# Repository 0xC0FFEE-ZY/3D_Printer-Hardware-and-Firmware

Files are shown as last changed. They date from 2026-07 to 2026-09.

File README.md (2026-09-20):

# 0xC0FFEE_ZY_3DPrinter

> **本仓库所有硬件已制作出实物并正常运行。** 

自制的 3D 打印机开源项目，包含整机三维建模、主板与电机驱动电路设计、Marlin 固件、CAD 结构件等。

- 可观看视频：https://b23.tv/UroBLIZ

## 仓库内容

| 目录 / 文件 | 说明 |
| --- | --- |
| `三维建模` | 本 3D 打印机整体三维结构建模；打印机屏幕外壳（适用于 MKS TFT35） |
| `硬件设计_工程文件（原理图+PCB）` | 嘉立创工程，本 3D 打印机的主板、电机驱动电路设计 |
| `Chinese_Version_Configured_Marlin2.1.3` | 本打印机配套固件 |
| `CAD图纸_3D打印机结构件` | 本打印机的一些结构件，可以找商家加工定制 |
| `XY_DrawCircles` | XY 轴测试程序 |

## 教程视频

关于本 3D 打印机详细的机械设计、电路设计介绍，可访问：https://b23.tv/Fq90FVm

视频中包括本 3D 打印机的结构三维动画，使用Solidworks运动算例制作。

- B站用户名 **0xC0FFEE_ZY**（抖音同名）

## 版权与许可

- Copyright (C) 2026 0xC0FFEE_ZY
- 本项目硬件电路及机械结构由 0xC0FFEE_ZY 设计。
- 软件基于 Marlin 固件（Copyright (C) Camiel Gubbels / Erik van der Zalm / MarlinFirmware，GPLv3 许可）。
- 本项目同样遵循 [GPLv3]许可。
- 如引用、转载或分发，须保留本版权声明和署名。
- 项目仓库：<https://github.com/0xC0FFEE-ZY/3D_Printer-Hardware-and-Firmware>
- 立创开源硬件平台：<https://oshwhub.com/zy_202411/zi-zhi-3d-da-yin-ji-ying-jian-dian-lu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>

                                                                   2026.9.20 By 0xC0FFEE_ZY

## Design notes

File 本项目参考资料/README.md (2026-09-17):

#
# 参考资料
#

本文件夹是本人制作这台3D打印机时参考过的一些资料，包括芯片手册，一些开源电路原理图等。希望对你们有些帮助。

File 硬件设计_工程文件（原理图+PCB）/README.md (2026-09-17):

 ================================================================================================================
 # Copyright (C) 2026 0xC0FFEE_ZY
 #
 # 本文件夹为 3D 打印机硬件工程文件，可配套教程视频使用。
 # 包括 步进电机驱动，打印机主板、线路转接板 的硬件工程文件，使用 嘉立创EDA专业版 绘制。
 #
 # 本文件夹提供了电路原理图 PDF 版本，可以快速浏览原理图。
 #
 # 硬件工程开源遵循GPLv3许可
 # 如引用、转载或分发，必须保留本版权声明和署名。
 #
 # 作者：0xC0FFEE_ZY
 # 2026.6.19
 ================================================================================================================

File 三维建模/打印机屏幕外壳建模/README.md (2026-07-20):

#
# 3D打印机屏幕外壳建模文件
#

这是本人的3D打印机屏幕外壳建模文件，包含4个零件和一个装配体文件。  适用于MKS TFT35串口屏（SD卡侧插版）

屏幕外壳总共由3个零件组成。装配体演示了3个零件之间的配合关系，安装的时候可以参考。

                                                                       0xC0FFEE_ZY
                                                                       2026.7.21

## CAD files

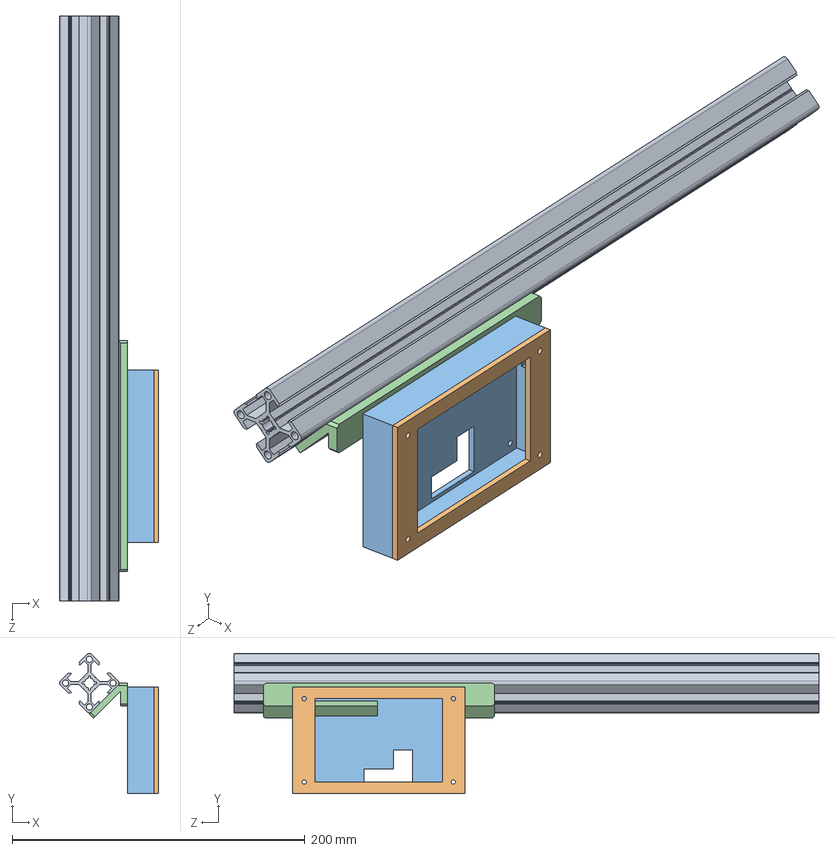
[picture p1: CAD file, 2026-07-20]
三维建模/打印机屏幕外壳建模/打印机屏幕外壳装配体.SLDASM
67.6 x 96.0 x 400.0 mm
屏幕座子支架
打印机屏幕底板
屏幕上盖
TXCK-H6-3030-L400

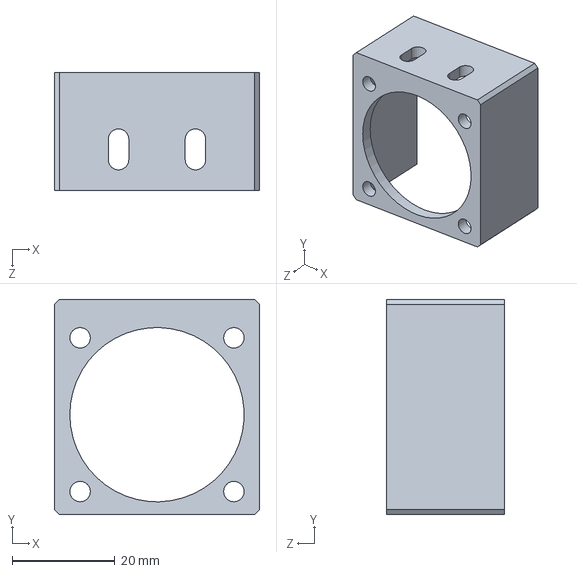
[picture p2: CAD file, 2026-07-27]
三维建模/喉管风扇外壳_风扇固定.SLDPRT
40.0 x 42.0 x 23.0 mm

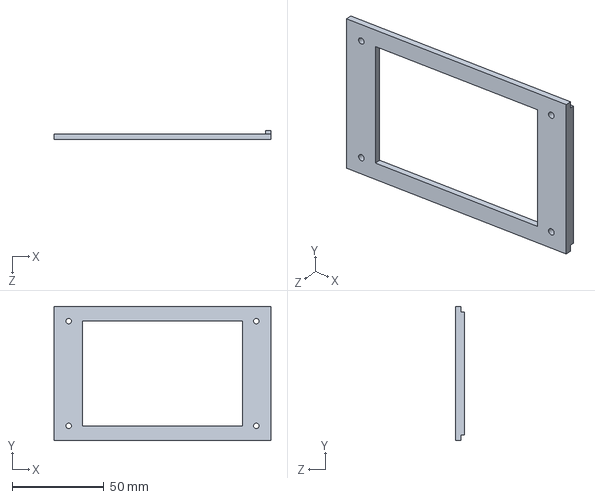
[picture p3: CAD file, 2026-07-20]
三维建模/打印机屏幕外壳建模/零件/屏幕上盖.SLDPRT
118.0 x 73.0 x 5.00 mm

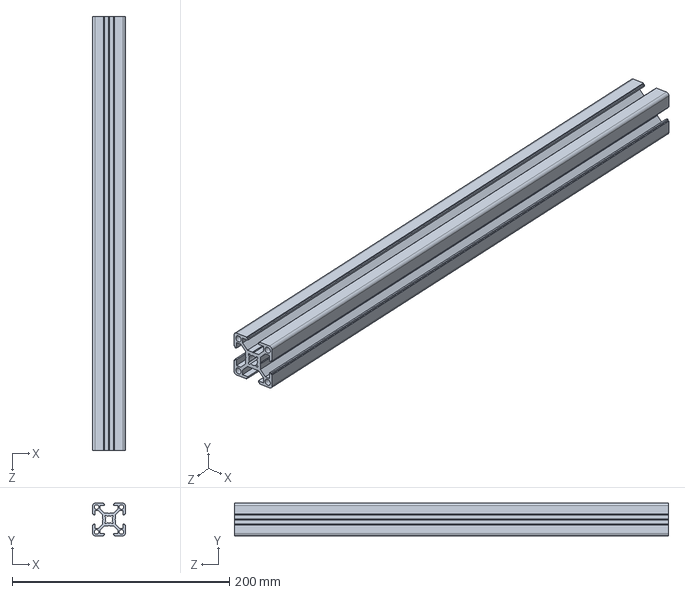
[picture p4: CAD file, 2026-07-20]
三维建模/打印机屏幕外壳建模/零件/TXCK-H6-3030-L400.SLDPRT
30.0 x 30.0 x 400.0 mm

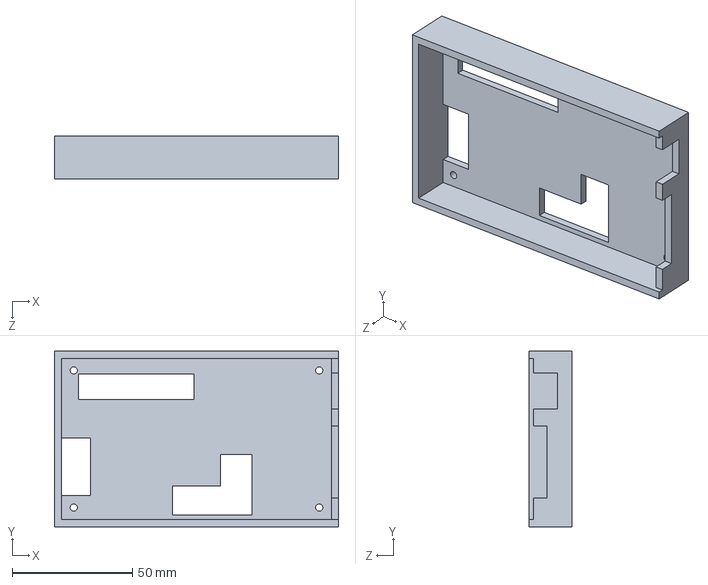
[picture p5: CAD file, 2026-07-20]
三维建模/打印机屏幕外壳建模/零件/打印机屏幕底板.SLDPRT
118.0 x 73.0 x 18.0 mm

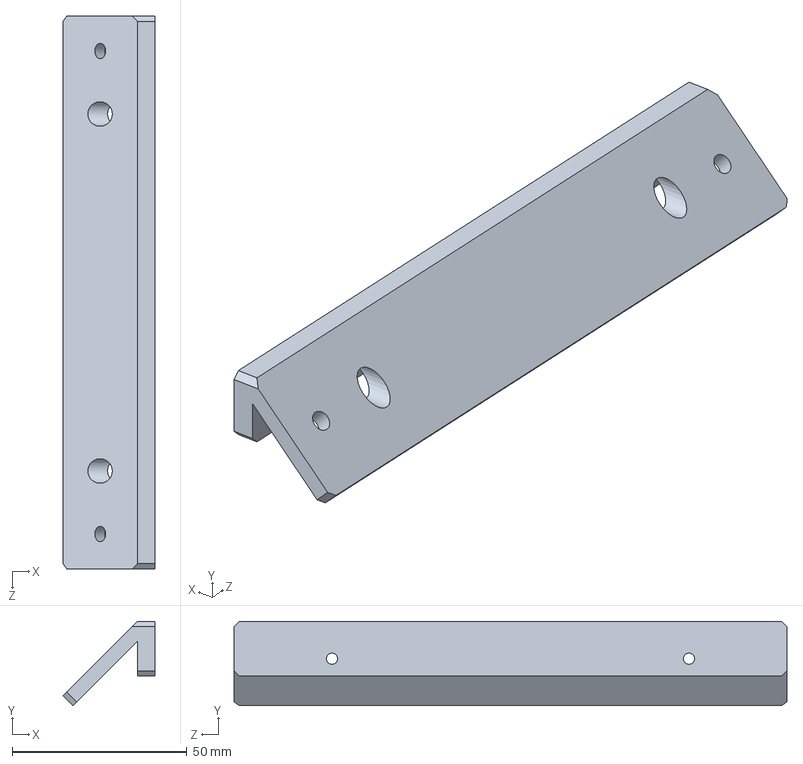
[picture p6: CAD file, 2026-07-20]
三维建模/打印机屏幕外壳建模/零件/屏幕座子支架.SLDPRT
26.2 x 24.0 x 158.0 mm

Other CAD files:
CAD图纸_3D打印机结构件/2mm不锈钢-挤出机固定件.dwg
CAD图纸_3D打印机结构件/4mm不锈钢-Z轴热床托板.dwg
CAD图纸_3D打印机结构件/10mm亚克力-电源托板.dwg
CAD图纸_3D打印机结构件/2mm不锈钢-XY滑块与十字导轨连接件.dwg
CAD图纸_3D打印机结构件/2mm不锈钢-喷嘴处连接件.dwg
CAD图纸_3D打印机结构件/2mm不锈钢-搭配GT2压板使用.dwg
CAD图纸_3D打印机结构件/2mm不锈钢-皮带张紧结构 .dwg
CAD图纸_3D打印机结构件/2mm不锈钢-42步进电机支架（适用于3030欧标铝型材）.dwg
CAD图纸_3D打印机结构件/2mm不锈钢-总电源插座固定件.dwg
CAD图纸_3D打印机结构件/2mm不锈钢-模型散热风扇固定件.dwg
CAD图纸_3D打印机结构件/2mm不锈钢-Z轴限位.dwg
CAD图纸_3D打印机结构件/2mm不锈钢-3DTouch支架.dwg
CAD图纸_3D打印机结构件/亚克力-打印机主板外壳.dwg

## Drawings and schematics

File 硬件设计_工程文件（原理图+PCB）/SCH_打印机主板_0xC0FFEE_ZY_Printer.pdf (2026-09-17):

# 24V转12V BUCK电源

# 跳线帽接3.3V

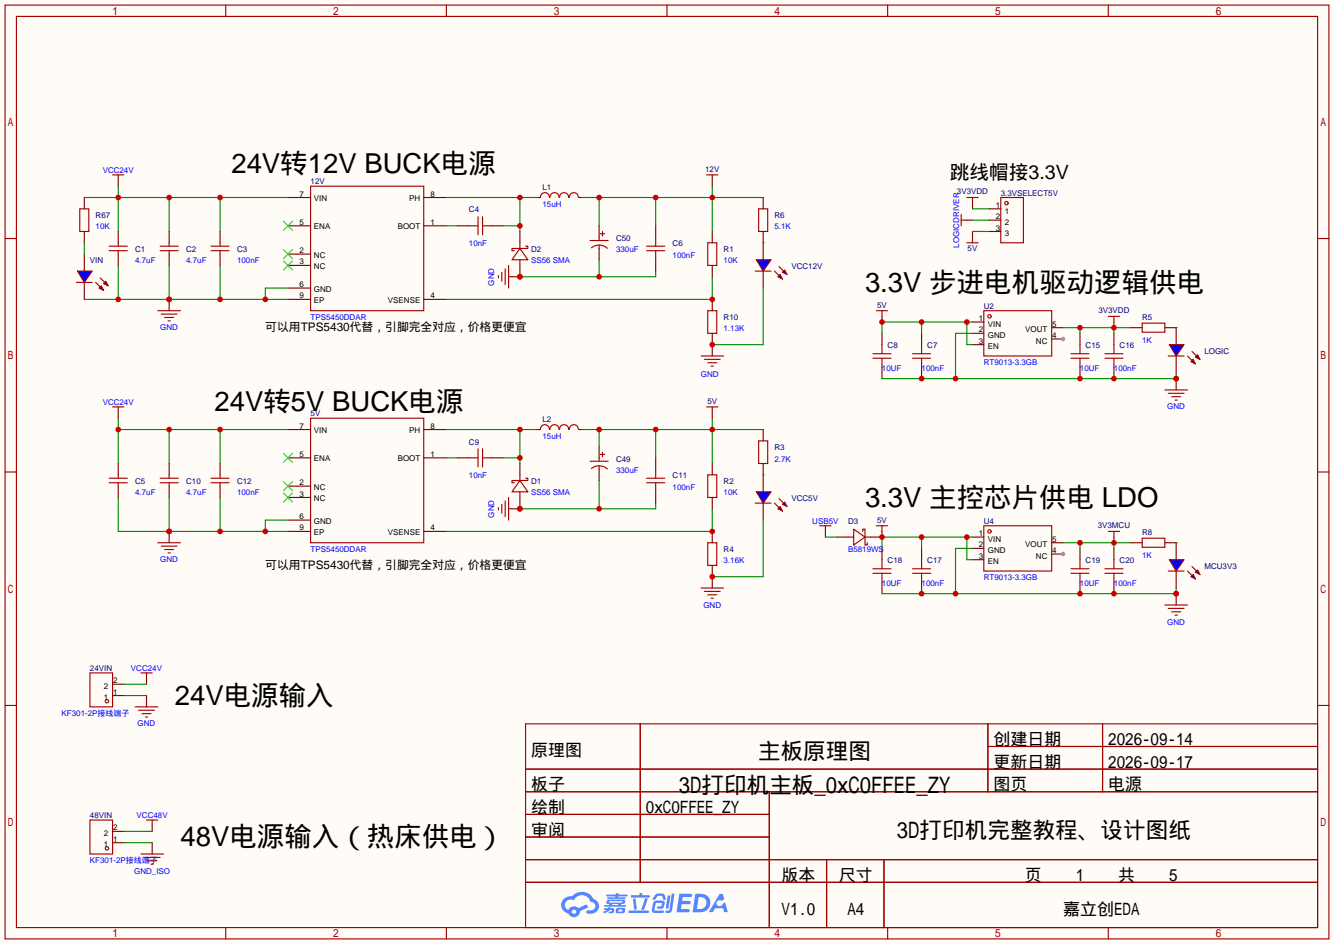
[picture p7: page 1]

原理图 | 主板原理图 | 创建日期 | 2026-09-14
板子 | 3D打印机主板_0xC0FFEE_ZY | 图页 | 电源
绘制 | 0xC0FFEE_ZY | 3D打印机完整教程、设计图纸
审阅

更新日期 | 2026-09-17

V1.0 | A4 | 嘉立创EDA

# 屏幕（串口）

MCU STM32F407VET6 | 备用串口

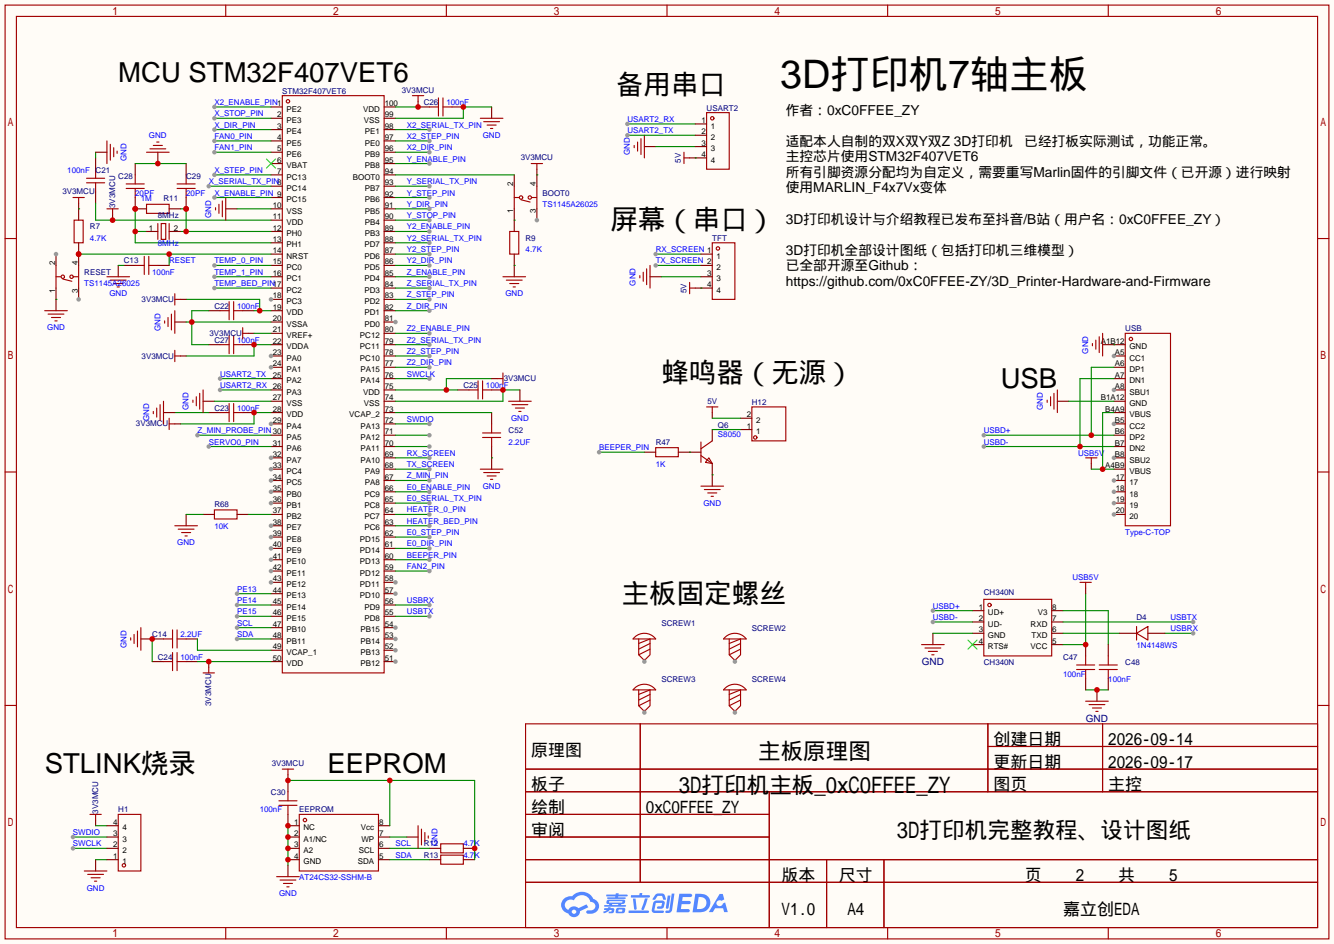
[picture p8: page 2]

3D打印机全部设计图纸（包括打印机三维模型）
已全部开源至Github：
https://github.com/0xC0FFEE-ZY/3D_Printer-Hardware-and-Firmware

USB
VBUS A4B9 SBU2 B8 DN2 B7 DP2 B6 CC2 B5 VBUS B4A9 GND B1A12 SBU1 A8 DN1 A7 DP1 A6 CC1 A5 GND A1B12

原理图 | 主板原理图 | 创建日期 | 2026-09-14
板子 | 3D打印机主板_0xC0FFEE_ZY | 图页 | 主控
绘制 | 0xC0FFEE_ZY | 3D打印机完整教程、设计图纸
审阅

更新日期 | 2026-09-17

# 热端（喷嘴）加热控制 腔体风扇

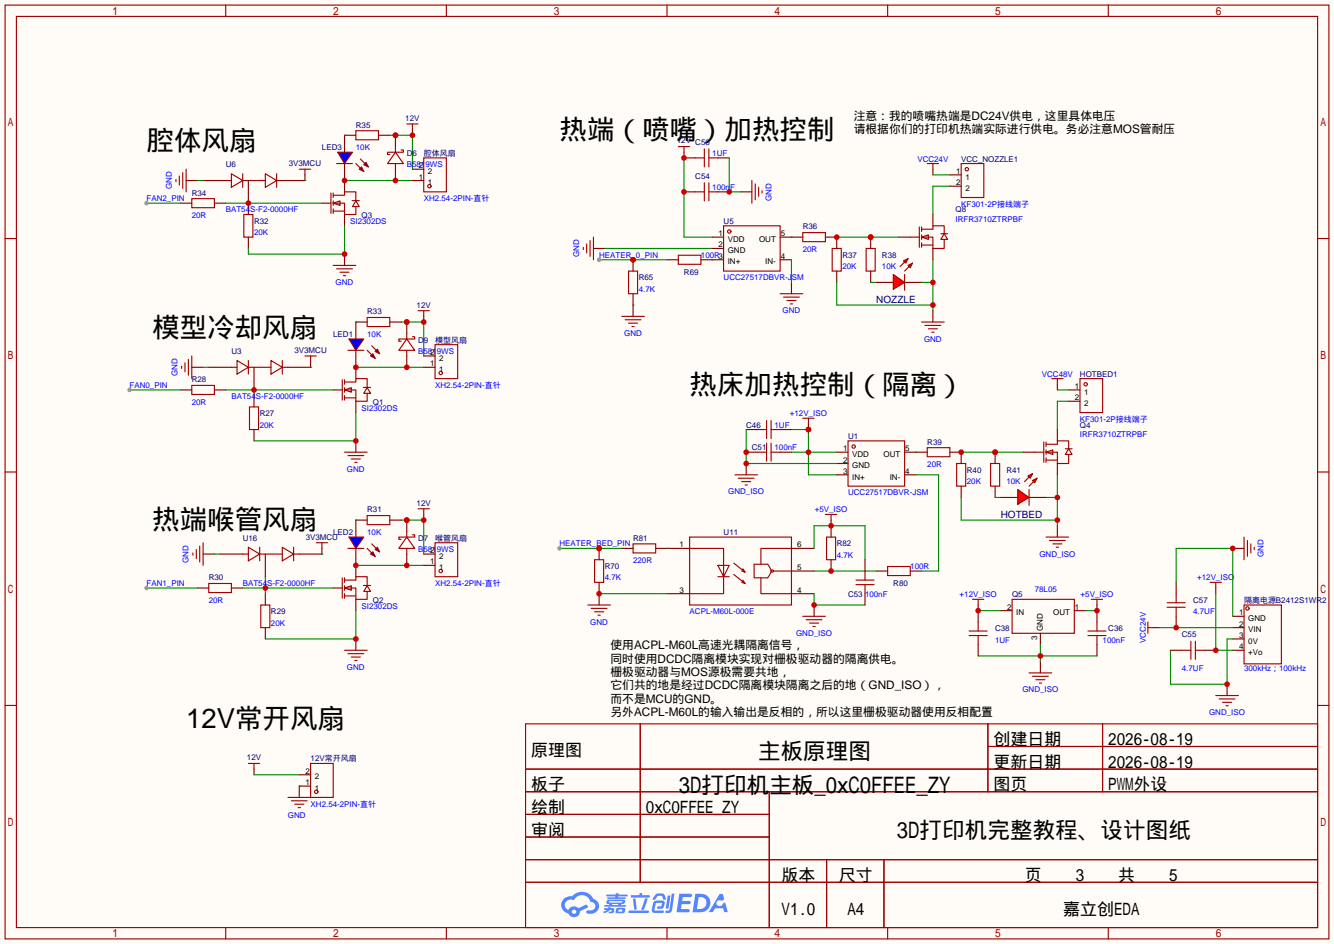
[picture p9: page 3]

原理图 | 主板原理图 | 创建日期 | 2026-08-19
板子 | 3D打印机主板_0xC0FFEE_ZY | 图页 | PWM外设
绘制 | 0xC0FFEE_ZY | 3D打印机完整教程、设计图纸
审阅

更新日期 | 2026-08-19

# X轴电机 Z轴电机

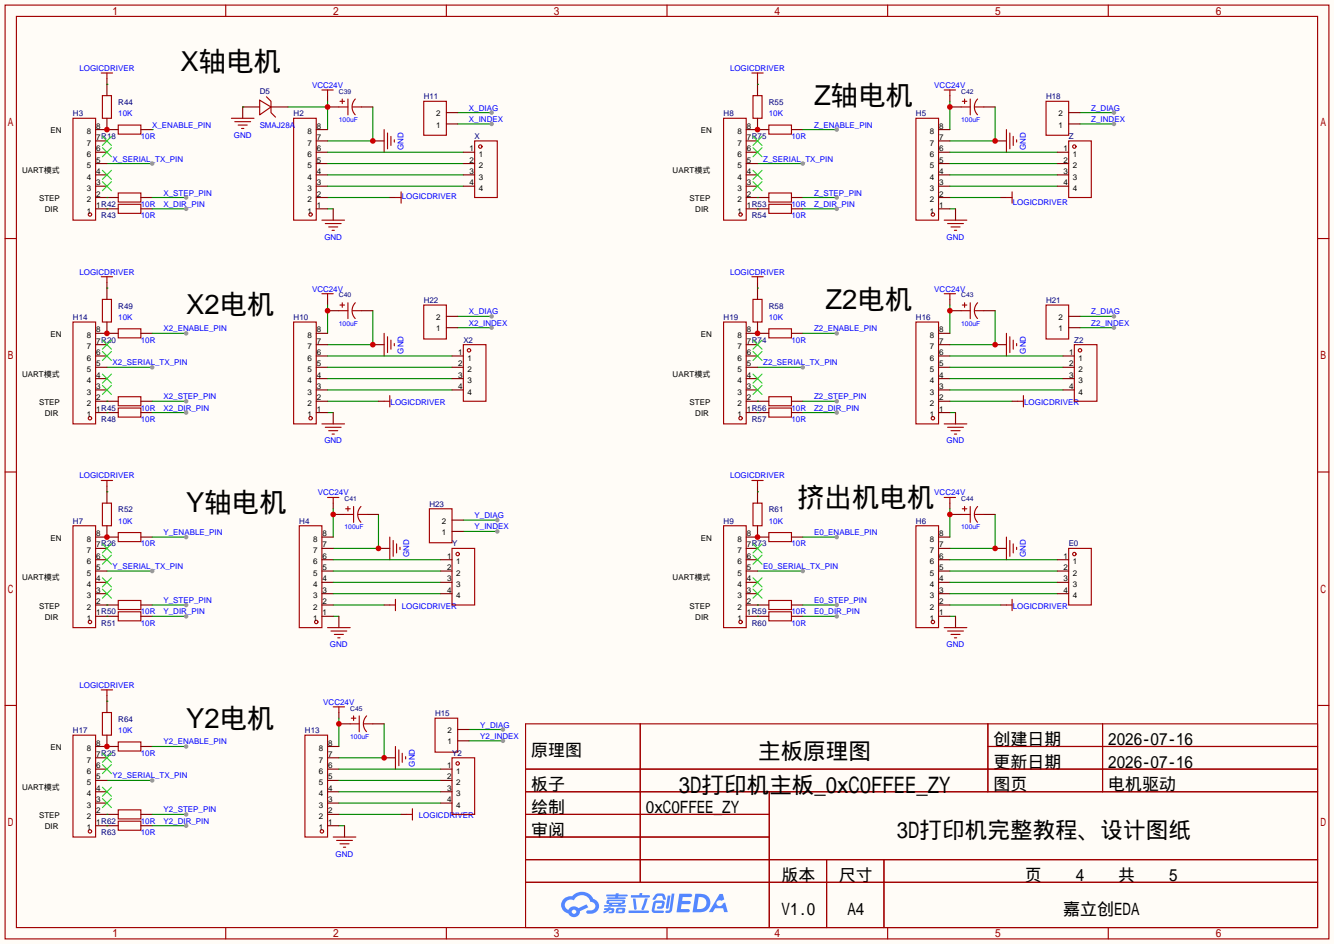
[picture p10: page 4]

原理图 | 主板原理图 | 创建日期 | 2026-07-16
板子 | 3D打印机主板_0xC0FFEE_ZY | 图页 | 电机驱动
绘制 | 0xC0FFEE_ZY | 3D打印机完整教程、设计图纸
审阅

更新日期 | 2026-07-16

热端喉管温度传感器 | 打印机舱体温度传感器 | 热床温度传感器

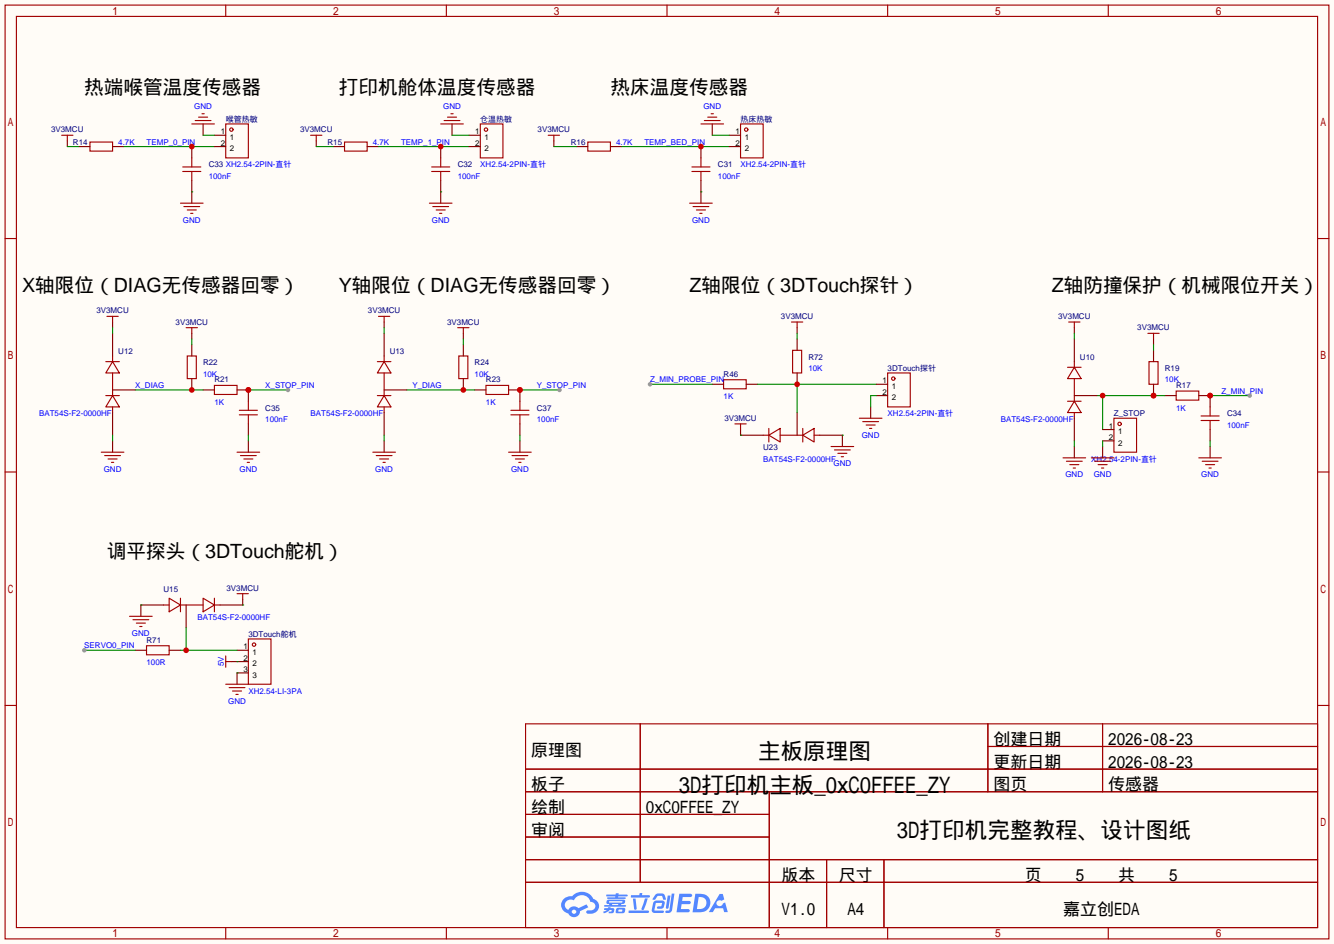
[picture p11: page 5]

原理图 | 主板原理图 | 创建日期 | 2026-08-23
板子 | 3D打印机主板_0xC0FFEE_ZY | 图页 | 传感器
绘制 | 0xC0FFEE_ZY | 3D打印机完整教程、设计图纸
审阅

更新日期 | 2026-08-23

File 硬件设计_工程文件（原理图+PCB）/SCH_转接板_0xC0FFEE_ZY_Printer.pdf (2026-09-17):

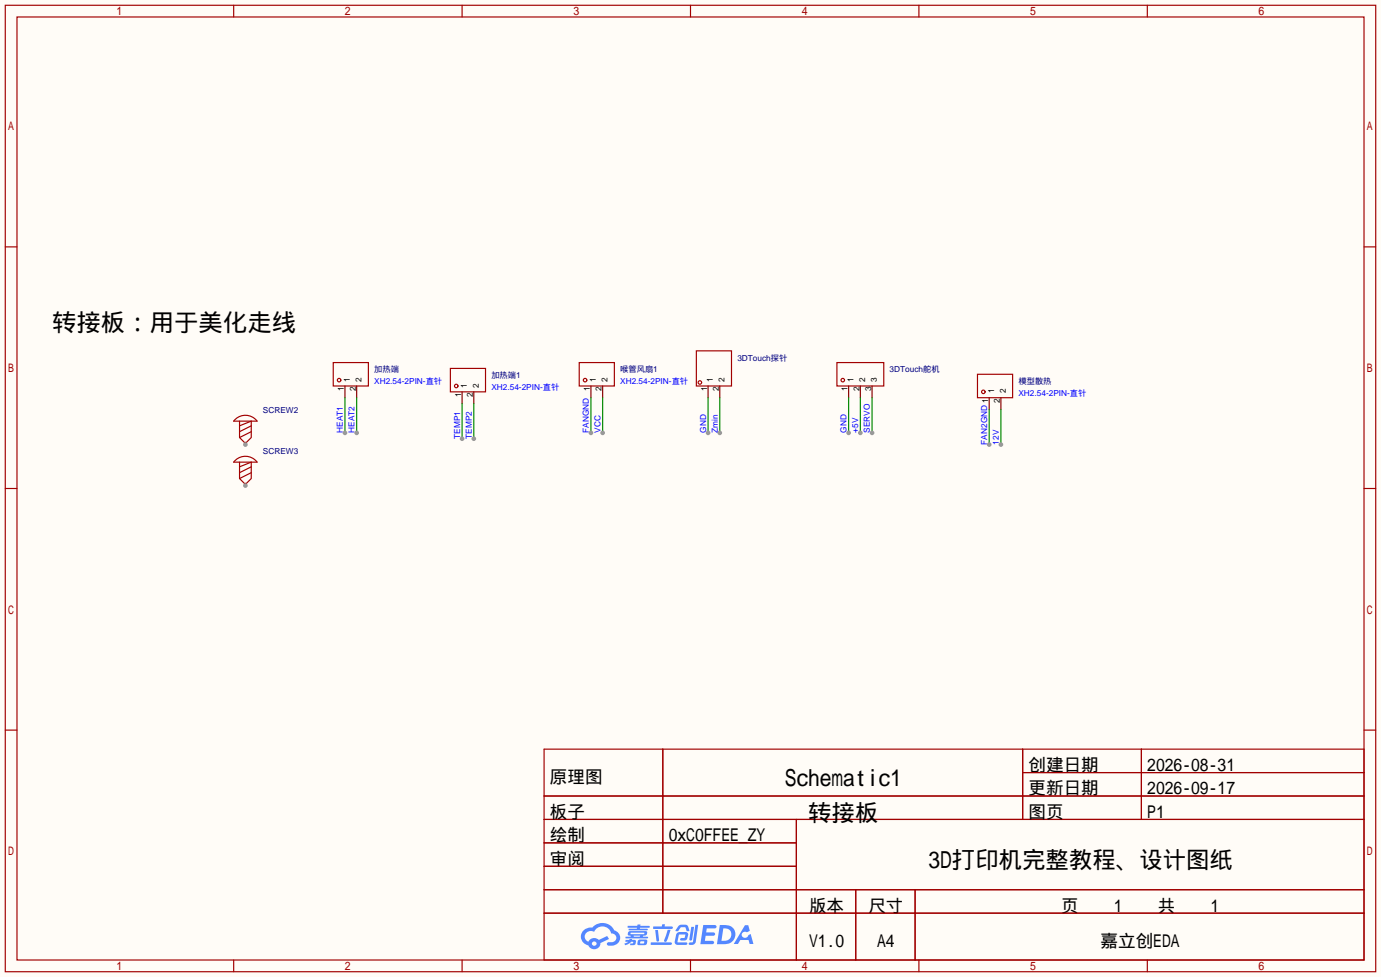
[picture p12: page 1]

原理图 | Schematic1 | 创建日期 | 2026-08-31

更新日期 | 2026-09-17

板子 | 转接板 | 图页 | P1
绘制 | 0xC0FFEE_ZY | 3D打印机完整教程、设计图纸
审阅

V1.0 | A4 | 嘉立创EDA

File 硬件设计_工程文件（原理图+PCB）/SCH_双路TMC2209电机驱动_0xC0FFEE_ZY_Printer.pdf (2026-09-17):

# 双路TMC2209步进电机驱动

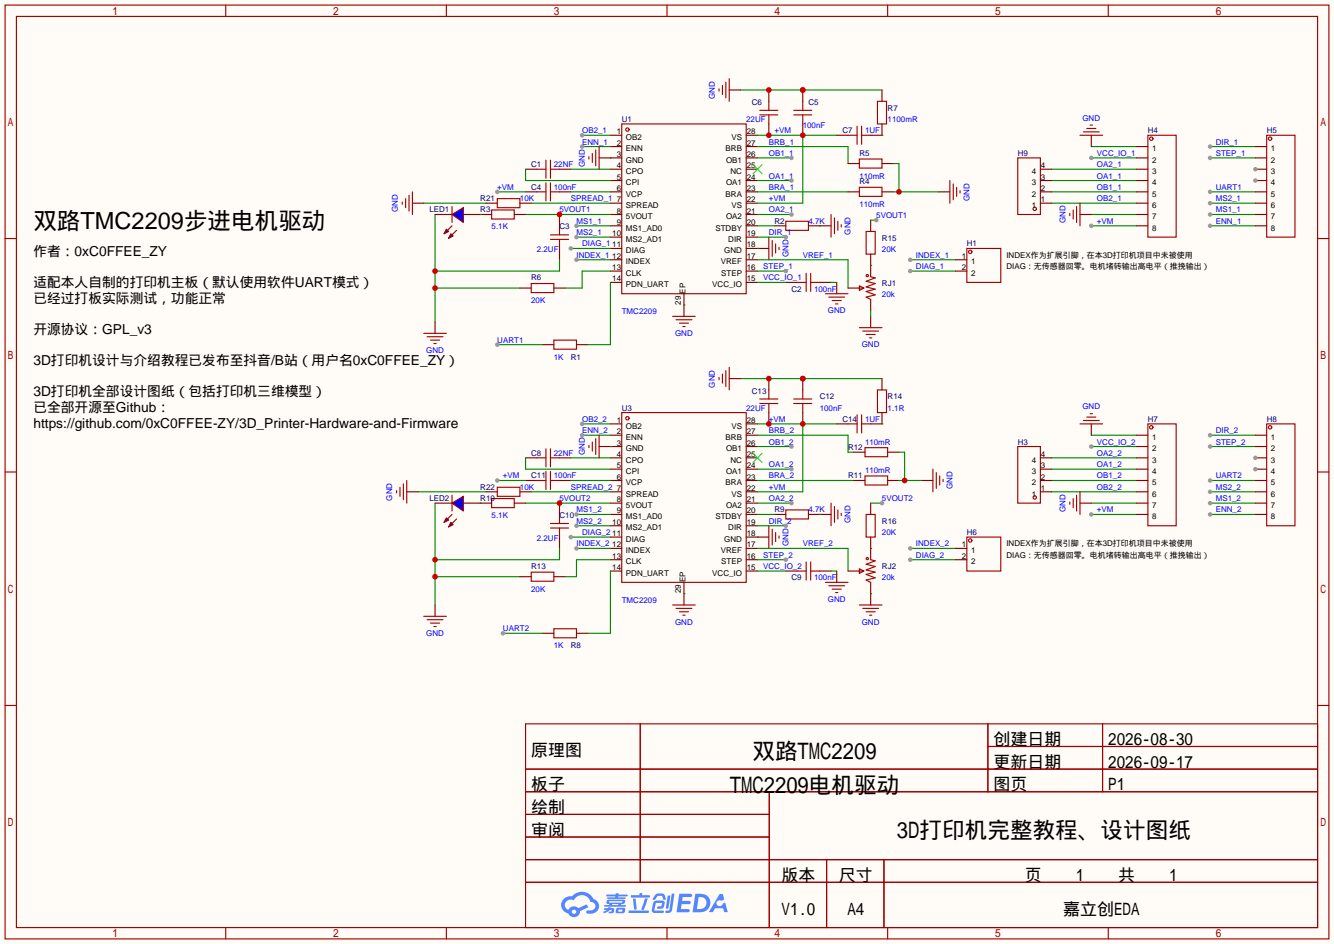
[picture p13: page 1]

INDEX作为扩展引脚，在本3D打印机项目中未被使用
DIAG：无传感器回零。电机堵转输出高电平（推挽输出）

3D打印机全部设计图纸（包括打印机三维模型）
已全部开源至Github：
https://github.com/0xC0FFEE-ZY/3D_Printer-Hardware-and-Firmware

原理图 | 双路TMC2209 | 创建日期 | 2026-08-30
板子 | TMC2209电机驱动 | 图页 | P1
绘制 | | 3D打印机完整教程、设计图纸
审阅

更新日期 | 2026-09-17

V1.0 | A4 | 嘉立创EDA

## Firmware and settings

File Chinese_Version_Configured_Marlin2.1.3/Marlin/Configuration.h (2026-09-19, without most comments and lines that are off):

#pragma once
#define CONFIGURATION_H_VERSION 02010300
#define STRING_CONFIG_H_AUTHOR "(none, default config)" // Original author or contributor.    // 原始作者 / 贡献者
  #define MOTHERBOARD BOARD_0xC0FFEE_ZY  // （译者注）：我的打印机主板为自制主板，主板芯片硬件引脚资源映射均为自定义，我在Marlin\src\pins\stm32f4目录下新建的头文件(pins_0xC0FFEE_ZY.h)里的宏定义映射了芯片硬件引脚功能
#define SERIAL_PORT 3
#define BAUDRATE 250000
#define SERIAL_PORT_2 1
#define BAUDRATE_2 57600   // :[2400, 9600, 19200, 38400, 57600, 115200, 250000, 500000, 1000000] Enable to override BAUDRATE  // 启用此项，用来覆盖（主串口）BAUDRATE
#define CUSTOM_MACHINE_NAME "0xC0FFEE_ZY_3DPrinter"
#define X_DRIVER_TYPE  TMC2209         // （译者注）：请根据你电机驱动实际硬件型号，选择上面列表里的驱动型号。我用的是TMC2209。
#define Y_DRIVER_TYPE  TMC2209
#define Z_DRIVER_TYPE  TMC2209
#define X2_DRIVER_TYPE TMC2209         // （译者注）：第二个X轴电机，如果你的打印机是双X电机，应当取消注释此行，启用X2电机。
#define Y2_DRIVER_TYPE TMC2209         // （译者注）：第二个Y轴电机，如果你的打印机是双Y电机，应当取消注释此行，启用Y2电机。
#define Z2_DRIVER_TYPE TMC2209         // （译者注）：第二个Z轴电机，如果你的打印机是双Z电机，应当取消注释此行，启用Z2电机。
#define E0_DRIVER_TYPE TMC2209         // （译者注）：挤出机电机
#define EXTRUDERS 1                           // （译者注）：我的打印机只用了一个挤出机（远程挤出）
#define DEFAULT_NOMINAL_FILAMENT_DIA 1.75     // （译者注）：我的打印机耗材直径是1.75mm
#define TEMP_SENSOR_0 1      // （译者注：这一行是挤出机的热敏电阻配置）
#define TEMP_SENSOR_1 0
#define TEMP_SENSOR_2 0
#define TEMP_SENSOR_3 0
#define TEMP_SENSOR_4 0
#define TEMP_SENSOR_5 0
#define TEMP_SENSOR_6 0
#define TEMP_SENSOR_7 0
#define TEMP_SENSOR_BED 1    // （译者注：这一行是热床的热敏电阻配置）
#define TEMP_SENSOR_PROBE 0
#define TEMP_SENSOR_CHAMBER 0
#define TEMP_SENSOR_COOLER 0
#define TEMP_SENSOR_BOARD 0
#define TEMP_SENSOR_SOC 0
#define TEMP_SENSOR_REDUNDANT 0
#define DUMMY_THERMISTOR_998_VALUE  25
#define DUMMY_THERMISTOR_999_VALUE 100
#if TEMP_SENSOR_IS_MAX_TC(0)
  #define MAX31865_SENSOR_OHMS_0      100 // (Ω) Typically 100 or 1000 (PT100 or PT1000)                     // (Ω) 通常为 100 或 1000（对应 PT100 或 PT1000 传感器）
  #define MAX31865_CALIBRATION_OHMS_0 430 // (Ω) Typically 430 for Adafruit PT100; 4300 for Adafruit PT1000  // (Ω) Adafruit PT100 通常为 430；Adafruit PT1000 通常为 4300
#endif
#if TEMP_SENSOR_IS_MAX_TC(1)
  #define MAX31865_SENSOR_OHMS_1      100
  #define MAX31865_CALIBRATION_OHMS_1 430
#endif
#if TEMP_SENSOR_IS_MAX_TC(2)
  #define MAX31865_SENSOR_OHMS_2      100
  #define MAX31865_CALIBRATION_OHMS_2 430
#endif
#if TEMP_SENSOR_IS_MAX_TC(BED)
  #define MAX31865_SENSOR_OHMS_BED      100
  #define MAX31865_CALIBRATION_OHMS_BED 430
#endif
#if HAS_E_TEMP_SENSOR
  #define TEMP_RESIDENCY_TIME         10  // (seconds) Time to wait for hotend to "settle" in M109               // (秒) M109 指令中等待热端温度稳定的延时时间
  #define TEMP_WINDOW                  1  // (°C) Temperature proximity for the "temperature reached" timer      // (°C) “温度达到”计时器的温度接近度
  #define TEMP_HYSTERESIS              3  // (°C) Temperature proximity considered "close enough" to the target  // (°C) 被认为“足够接近”目标的温度接近度
#endif
#if TEMP_SENSOR_BED
  #define TEMP_BED_RESIDENCY_TIME     10  // (seconds) Time to wait for bed to "settle" in M190                  // (秒) M190 指令中等待热床温度稳定的延时时间
  #define TEMP_BED_WINDOW              1  // (°C) Temperature proximity for the "temperature reached" timer      // (°C) “温度达到”计时器的温度接近度
  #define TEMP_BED_HYSTERESIS          3  // (°C) Temperature proximity considered "close enough" to the target  // (°C) 被认为“足够接近”目标的温度接近度
#endif
#if TEMP_SENSOR_CHAMBER
  #define TEMP_CHAMBER_RESIDENCY_TIME 10  // (seconds) Time to wait for chamber to "settle" in M191              // (秒) M191 指令中等待机箱温度稳定的延时时间
  #define TEMP_CHAMBER_WINDOW          1  // (°C) Temperature proximity for the "temperature reached" timer      // (°C) “温度达到”计时器的温度接近度
  #define TEMP_CHAMBER_HYSTERESIS      3  // (°C) Temperature proximity considered "close enough" to the target  // (°C) 被认为“足够接近”目标的温度接近度
#endif
#if TEMP_SENSOR_REDUNDANT
  #define TEMP_SENSOR_REDUNDANT_SOURCE    E1  // The sensor that will provide the redundant reading.           // 将提供冗余读数的传感器。
  #define TEMP_SENSOR_REDUNDANT_TARGET    E0  // The sensor that we are providing a redundant reading for.     // 我们正在为其提供冗余读数的传感器。
  #define TEMP_SENSOR_REDUNDANT_MAX_DIFF  10  // (°C) Temperature difference that will trigger a print abort.  //（°C）将触发打印中止的温度差异。
#endif
#define HEATER_0_MINTEMP   5                                  // （译者注：0号加热器的最低温度限制:5℃）
#define HEATER_1_MINTEMP   5
#define HEATER_2_MINTEMP   5
#define HEATER_3_MINTEMP   5
#define HEATER_4_MINTEMP   5
#define HEATER_5_MINTEMP   5
#define HEATER_6_MINTEMP   5
#define HEATER_7_MINTEMP   5
#define BED_MINTEMP        5
#define CHAMBER_MINTEMP    5
#define HEATER_0_MAXTEMP 275                                                        // （译者注：0号加热器的最高温度限制:275℃）
#define HEATER_1_MAXTEMP 275
#define HEATER_2_MAXTEMP 275
#define HEATER_3_MAXTEMP 275
#define HEATER_4_MAXTEMP 275
#define HEATER_5_MAXTEMP 275
#define HEATER_6_MAXTEMP 275
#define HEATER_7_MAXTEMP 275
#define BED_MAXTEMP      150
#define CHAMBER_MAXTEMP  60
#define HOTEND_OVERSHOOT 15   // (°C) Forbid temperatures over MAXTEMP - OVERSHOOT  //（°C）禁止设置超过 MAXTEMP - OVERSHOOT 的温度
#define BED_OVERSHOOT    10   // (°C) Forbid temperatures over MAXTEMP - OVERSHOOT  //（°C）禁止设置超过 MAXTEMP - OVERSHOOT 的温度
#define COOLER_OVERSHOOT  2   // (°C) Forbid temperatures closer than OVERSHOOT     //（°C）禁止设置接近 OVERSHOOT 的温度
#define PIDTEMP           // See the PID Tuning Guide at https://reprap.org/wiki/PID_Tuning        // 参阅PID调参指南，网址：https://reprap.org/wiki/PID_Tuning
#define PID_MAX  255      // Limit hotend current while PID is active (see PID_FUNCTIONAL_RANGE below); 255=full current  // PID激活时限制热端电流（见下文PID_FUNCTIONAL_RANGE）；255=全电流
#define PID_K1     0.95   // Smoothing factor within any PID loop  // PID循环内的平滑因子
    #define DEFAULT_Kp  22.20
    #define DEFAULT_Ki   1.08
    #define DEFAULT_Kd 114.00
#define MAX_BED_POWER 255 // limits duty cycle to bed; 255=full current
#define MAX_CHAMBER_POWER 255 // limits duty cycle to chamber heater; 255=full current  // 限制腔体加热器的工作占空比；255 = 满电流/满功率
  #define PID_FUNCTIONAL_RANGE 20 // If the temperature difference between the target temperature and the actual temperature
#define PREVENT_COLD_EXTRUSION
#define EXTRUDE_MINTEMP 170
#define PREVENT_LENGTHY_EXTRUDE
#define EXTRUDE_MAXLENGTH 200    //（译者注）：每次手动挤出，最长只能出 200mm
#define THERMAL_PROTECTION_HOTENDS // Enable thermal protection for all extruders       // 为所有挤出机启用热保护功能
#define THERMAL_PROTECTION_BED     // Enable thermal protection for the heated bed      // 为热床启用热保护功能
#define THERMAL_PROTECTION_CHAMBER // Enable thermal protection for the heated chamber  // 为加热腔体启用热保护功能
#define THERMAL_PROTECTION_COOLER  // Enable thermal protection for the laser cooling   // 为激光冷却系统启用热保护功能
#define ENDSTOPPULLUPS
#define X_MIN_ENDSTOP_HIT_STATE HIGH
#define X_MAX_ENDSTOP_HIT_STATE HIGH
#define Y_MIN_ENDSTOP_HIT_STATE HIGH
#define Y_MAX_ENDSTOP_HIT_STATE HIGH
#define Z_MIN_ENDSTOP_HIT_STATE HIGH
#define Z_MAX_ENDSTOP_HIT_STATE HIGH
#define I_MIN_ENDSTOP_HIT_STATE HIGH
#define I_MAX_ENDSTOP_HIT_STATE HIGH
#define J_MIN_ENDSTOP_HIT_STATE HIGH
#define J_MAX_ENDSTOP_HIT_STATE HIGH
#define K_MIN_ENDSTOP_HIT_STATE HIGH
#define K_MAX_ENDSTOP_HIT_STATE HIGH
#define U_MIN_ENDSTOP_HIT_STATE HIGH
#define U_MAX_ENDSTOP_HIT_STATE HIGH
#define V_MIN_ENDSTOP_HIT_STATE HIGH
#define V_MAX_ENDSTOP_HIT_STATE HIGH
#define W_MIN_ENDSTOP_HIT_STATE HIGH
#define W_MAX_ENDSTOP_HIT_STATE HIGH
#define Z_MIN_PROBE_ENDSTOP_HIT_STATE HIGH       //（译者注）：根据你的探针实际情况进行配置。
#define DEFAULT_AXIS_STEPS_PER_UNIT   { 160, 160, 3200, 562 }    //（译者注：大括号里四个参数依次为：X 轴，Y 轴，Z 轴，挤出机 E0 的步数/毫米。根据你的机器实际情况修改这些数值，确保打印机运动的准确性。）
#define EDITABLE_STEPS_PER_UNIT
#define DEFAULT_MAX_FEEDRATE          { 300, 300, 5, 25 }   //（译者注：四个参数依次为X、Y、Z、挤出机的最大运动速度，单位：mm/s。）
#define DEFAULT_MAX_ACCELERATION      { 3000, 3000, 100, 10000 }  //（译者注：四个参数依次为X、Y、Z、挤出机的最大加速度，单位：mm/s²。）
#define DEFAULT_ACCELERATION          3000    // X, Y, Z and E acceleration for printing moves         // 打印移动时 X、Y、Z、E 轴的加速度
#define DEFAULT_RETRACT_ACCELERATION  3000    // E acceleration for retracts                           // 回抽时 E 轴（挤出机）的加速度
#define DEFAULT_TRAVEL_ACCELERATION   3000    // X, Y, Z acceleration for travel (non printing) moves  // 空移（非打印移动）时 X、Y、Z 轴的加速度
  #define JUNCTION_DEVIATION_MM 0.013 // (mm) Distance from real junction edge  // (mm) 距离真实拐角顶点的距离（圆弧偏移量）
  #define JD_HANDLE_SMALL_SEGMENTS    // Use curvature estimation instead of just the junction angle
#define USE_PROBE_FOR_Z_HOMING             // 强制使用 Z 探针（3DTouch)进行归位，不开启则默认使用Z_MIN_PIN进行归位！（如果你的Z探针引脚和Z_MIN_PIN是独立的两个引脚，请务必开启此！）
#define BLTOUCH
#define NOZZLE_TO_PROBE_OFFSET { -32, -10, -2.2 }
#define PROBING_TOOL 0
#define PROBING_MARGIN 10
#define XY_PROBE_FEEDRATE    (133*60) // (mm/min)
#define Z_PROBE_FEEDRATE_FAST  (4*60) // (mm/min)
#define Z_PROBE_FEEDRATE_SLOW (Z_PROBE_FEEDRATE_FAST / 2) // (mm/min)
#define Z_CLEARANCE_DEPLOY_PROBE   10 // (mm) Z Clearance for Deploy/Stow                                                       // s探头展开 / 收回时的 Z 轴安全间隙（毫米）
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

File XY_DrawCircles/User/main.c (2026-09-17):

/*=================================测试程序================================*/
/*
* 本程序用于测试3D打印机XY轴联动功能。
* 它可以让XY轴重复画圆圈。如果打印机XY轴安装不合理可能会导致电机卡住。
*
* 本程序实现了一个基于DDA算法的圆弧插补，控制两轴步进电机绘制一个半径为50mm的圆。
* 
* 使用STM32F103C8T6单片机，搭配A4988步进电机驱动模块，连接X、Y轴步进电机。
* 步进电机步距角是0.9°，驱动采用全步进（无细分，A4988的MS1、MS2、MS3引脚直接悬空
* 就行，减少繁琐的接线）。SLEEP，RESET和VDD接3.3V高电平，VMOT接24V电源。单片机3.3V供电。
* 注意单片机和驱动模块的电源共地。
* Keil5工程，基于标准库。下方所有程序均由AI生成。
*                                                       0xC0FFEE_ZY
*                                                       2026.5.18
*/

#include "stm32f10x.h"

/* ---------- 引脚定义 ---------- */
#define X_STEP_PIN    GPIO_Pin_0
#define X_DIR_PIN     GPIO_Pin_1
#define X_EN_PIN      GPIO_Pin_2
#define X_PORT        GPIOA

#define Y_STEP_PIN    GPIO_Pin_3
#define Y_DIR_PIN     GPIO_Pin_4
#define Y_EN_PIN      GPIO_Pin_5
#define Y_PORT        GPIOA

/* ---------- 机械参数 ---------- */
#define RADIUS_MM     50
#define PULSE_PER_MM  10            // 0.1mm/脉冲
#define RADIUS_PULSE  (RADIUS_MM * PULSE_PER_MM) // 500
#define ACC_MAX       1024          // 累加器上限（2^10，需 > 2*R）
#define TIM_PERIOD    750          // 插补频率 ≈ 1333.33 Hz

/* 方向电平宏（根据实际接线可调整） */
#define X_DIR_POSITIVE   Bit_SET
#define X_DIR_NEGATIVE   Bit_RESET
#define Y_DIR_POSITIVE   Bit_SET
#define Y_DIR_NEGATIVE   Bit_RESET

/* ---------- 全局变量（全部 volatile） ---------- */
volatile int32_t X = RADIUS_PULSE;   // 当前X坐标（脉冲数）
volatile int32_t Y = 0;              // 当前Y坐标
volatile int32_t X_acc = 0;          // X积分累加器
volatile int32_t Y_acc = 0;          // Y积分累加器
volatile uint8_t quadrant = 0;       // 当前象限：0=I,1=II,2=III,3=IV
volatile uint8_t started = 0;        // 是否离开起点

/* 简易微秒延时 */
static void delay_us(uint32_t us) {
    while (us--) {
        for (volatile int i = 0; i < 8; i++) __NOP();
    }
}

/* 根据象限设置X、Y的方向（在脉冲输出前调用） */
static void set_dir_by_quadrant(void) {
    switch (quadrant) {
        case 0: // 第一象限：X负，Y正
            GPIO_WriteBit(X_PORT, X_DIR_PIN, X_DIR_NEGATIVE);
            GPIO_WriteBit(Y_PORT, Y_DIR_PIN, Y_DIR_POSITIVE);
            break;
        case 1: // 第二象限：X负，Y负
            GPIO_WriteBit(X_PORT, X_DIR_PIN, X_DIR_NEGATIVE);
            GPIO_WriteBit(Y_PORT, Y_DIR_PIN, Y_DIR_NEGATIVE);
            break;
        case 2: // 第三象限：X正，Y负
            GPIO_WriteBit(X_PORT, X_DIR_PIN, X_DIR_POSITIVE);
            GPIO_WriteBit(Y_PORT, Y_DIR_PIN, Y_DIR_NEGATIVE);
            break;
        case 3: // 第四象限：X正，Y正
            GPIO_WriteBit(X_PORT, X_DIR_PIN, X_DIR_POSITIVE);
            GPIO_WriteBit(Y_PORT, Y_DIR_PIN, Y_DIR_POSITIVE);
            break;
    }
}

/* 根据当前坐标更新象限（坐标更新后调用） */
static void update_quadrant(int32_t x, int32_t y) {
    if (x > 0 && y >= 0)        quadrant = 0;
    else if (x <= 0 && y > 0)   quadrant = 1;
    else if (x < 0 && y <= 0)   quadrant = 2;
    else if (x >= 0 && y < 0)   quadrant = 3;
    // 在坐标轴上归属明确，避免歧义
}

/* 定时器2中断：DDA圆弧插补 */
void TIM2_IRQHandler(void) {
    if (TIM_GetITStatus(TIM2, TIM_IT_Update) == RESET) return;
    TIM_ClearITPendingBit(TIM2, TIM_IT_Update);

    // 1. 读取当前坐标
    int32_t x_now = X;
    int32_t y_now = Y;

    // 2. 被积函数：Jx = |Y|，Jy = |X|
    int32_t Jx = (y_now >= 0) ? y_now : -y_now;
    int32_t Jy = (x_now >= 0) ? x_now : -x_now;

    // 3. 累加并检测溢出
    uint8_t x_pulse = 0, y_pulse = 0;
    X_acc += Jx;
    if (X_acc >= ACC_MAX) {
        X_acc -= ACC_MAX;
        x_pulse = 1;
    }
    Y_acc += Jy;
    if (Y_acc >= ACC_MAX) {
        Y_acc -= ACC_MAX;
        y_pulse = 1;
    }

    // 4. 输出脉冲（先设置方向，再发脉冲）
    if (x_pulse || y_pulse) {
        set_dir_by_quadrant();  // 基于旧象限的方向

        if (x_pulse) {
            GPIO_SetBits(X_PORT, X_STEP_PIN);
            delay_us(2);
            GPIO_ResetBits(X_PORT, X_STEP_PIN);
        }
        if (y_pulse) {
            GPIO_SetBits(Y_PORT, Y_STEP_PIN);
            delay_us(2);
            GPIO_ResetBits(Y_PORT, Y_STEP_PIN);
        }

        // 5. 更新坐标（根据当前象限方向）
        if (x_pulse) {
            if (quadrant == 0 || quadrant == 1)  x_now--;  // 负方向
            else                                  x_now++;
        }
        if (y_pulse) {
            if (quadrant == 0 || quadrant == 3)  y_now++;  // 正方向
            else                                  y_now--;
        }

        X = x_now;
        Y = y_now;

        // 6. 更新象限，供下次使用
        update_quadrant(x_now, y_now);
    }

    // 7. 检测整圆完成（回到起点）
    if (X != RADIUS_PULSE || Y != 0) started = 1;
    if (started && X == RADIUS_PULSE && Y == 0) {
        TIM_Cmd(TIM2, DISABLE);  // 停止插补
    }
}

/* GPIO初始化 */
static void GPIO_Config(void) {
    RCC_APB2PeriphClockCmd(RCC_APB2Periph_GPIOA, ENABLE);
    GPIO_InitTypeDef g = {
        .GPIO_Speed = GPIO_Speed_50MHz,
        .GPIO_Mode = GPIO_Mode_Out_PP,
        .GPIO_Pin = X_STEP_PIN | X_DIR_PIN | X_EN_PIN
    };
    GPIO_Init(GPIOA, &g);
    g.GPIO_Pin = Y_STEP_PIN | Y_DIR_PIN | Y_EN_PIN;
    GPIO_Init(GPIOA, &g);

    // 初始状态：STEP低，EN低（使能）
    GPIO_ResetBits(X_PORT, X_STEP_PIN | X_EN_PIN);
    GPIO_ResetBits(Y_PORT, Y_STEP_PIN | Y_EN_PIN);
}

/* 定时器2初始化 */
static void TIM2_Config(void) {
    RCC_APB1PeriphClockCmd(RCC_APB1Periph_TIM2, ENABLE);
    TIM_TimeBaseInitTypeDef t = {
        .TIM_Period = TIM_PERIOD - 1,
        .TIM_Prescaler = 72 - 1,     // 72MHz -> 1MHz
        .TIM_ClockDivision = TIM_CKD_DIV1,
        .TIM_CounterMode = TIM_CounterMode_Up
    };
    TIM_TimeBaseInit(TIM2, &t);
    TIM_ITConfig(TIM2, TIM_IT_Update, ENABLE);

    NVIC_InitTypeDef n = {
        .NVIC_IRQChannel = TIM2_IRQn,
        .NVIC_IRQChannelPreemptionPriority = 0,
        .NVIC_IRQChannelSubPriority = 1,
        .NVIC_IRQChannelCmd = ENABLE
    };
    NVIC_Init(&n);
    TIM_Cmd(TIM2, ENABLE);
}

int main(void) {
    GPIO_Config();
    TIM2_Config();
    while (1) __WFI();
}

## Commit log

2026-05-13 Translated the heating PID annotations
    [Configuration.h]
2026-05-13 Translated the heating protection note.
    [Configuration.h]
2026-05-13 Translation --翻译了一些打印机架构（如CoreXY,三角洲架构）注释
    [Configuration.h]
2026-05-13 Translation--限位开关配置注释翻译
    [Configuration.h]
2026-05-13 Translation--翻译了打印机运动参数（加速度，速度等配置注释
    [Configuration.h]
2026-05-13 Translation--翻译自动调平配置并加入了一些调平探头介绍
    [Configuration.h]
2026-05-16 Translation--翻译了自动调平的一些配置注释
    [Configuration.h]
2026-05-16 Translation--安全配置
    [Configuration.h]
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2026-05-20 Translation--热床调平注释翻译
    [Configuration.h]
2026-05-20 Translation--进阶功能翻译（EEPROM，单位转换（温度/华氏度、毫米/英寸），喷嘴停靠等）
    [Configuration.h]
2026-05-20 Translation--喷头清洁相关配置注释翻译与解释
    [Configuration.h]
2026-05-20 Translation--打印统计数据、打印机密码锁配置注释翻译
    [Configuration.h]
2026-05-20 Translation--SD卡（脱机打印）配置注释翻译
    [Configuration.h]
2026-05-20 Translation--屏幕人机交互方式配置注释翻译
    [Configuration.h]
2026-05-20 Translation--蜂鸣器/扬声器反馈配置 翻译
    [Configuration.h]
2026-05-20 Translation--Marlin支持的LCD屏幕参数注释
    [Configuration.h]
2026-05-20 Translation--Marlin支持的OLED屏幕参数注释
    [Configuration.h]
2026-05-20 Translation--Marlin支持的可扩展用户界面（Extensible UI Displays）显示屏注释
    [Configuration.h]
2026-05-20 Translation--Marlin支持的TFT屏幕注释
    [Configuration.h]
2026-05-20 Translation--屏幕其他参数设置注释翻译
    [Configuration.h]
2026-05-20 Translation--其他配置（PWM调速风扇，RGB灯效，舵机）注释翻译
    [Configuration.h]
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2026-05-21 Translation--加热相关高级配置（Configuration_adv)注释翻译
    [Configuration_adv.h]
2026-05-21 Translation--挤出机、风扇相关高级配置(Configuration_adv)注释翻译
    [Configuration_adv.h]
2026-05-21 Translation--氛围灯、限位开关、双喷头高级配置(Configuration_adv)注释翻译
    [Configuration_adv.h]
2026-05-21 Translation--多步进电机参数配置（例如 双X双Y轴双Z）注释翻译
    [Configuration_adv.h]
2026-05-21 Translation--回零、归位高级配置(Configuration_adv)注释翻译
    [Configuration_adv.h]
2026-05-21 Translation--BLTouch自动调平相关高级配置(Configuration_adv)注释翻译
    [Configuration_adv.h]
2026-05-21 Translation--校准相关进阶配置(Configuration_adv)注释翻译
    [Configuration_adv.h]
2026-05-22 Translation--运动控制（包括振动补偿，电机细分，电流设置）进阶配置(Configuration_adv)注释翻译
    [Configuration_adv.h]
2026-05-22 Translation--屏幕高级配置(Configuration_adv)注释翻译
    [Configuration_adv.h]
2026-05-22 Translation--SD卡高级配置(Configuration_adv)注释翻译
    [Configuration_adv.h]
2026-05-22 Translation--断电续打(Configuration_adv)注释翻译
    [Configuration_adv.h]
2026-05-22 Translation--USB配置(Configuration_adv)注释翻译
    [Configuration_adv.h]
2026-05-22 Translation--屏幕额外优化(Configuration_adv)注释翻译
    [Configuration_adv.h]
2026-05-22 Translation-- 一些型号屏幕配置注释翻译
    [Configuration_adv.h]
2026-05-22 Translation--挤出机高级配置(Configuration_adv)注释翻译
    [Configuration_adv.h]
2026-05-22 Translation--调平高级配置(Configuration_adv)注释翻译
    [Configuration_adv.h]
2026-05-22 Translation--其他高级配置（圆弧插补优化打印、驱动脉冲宽度等）(Configuration_adv)注释翻译
    [Configuration_adv.h]
2026-05-22 Translation--缓冲区配置(Configuration_adv)注释翻译
    [Configuration_adv.h]
2026-05-22 Translation--工具切换高级配置(Configuration_adv)注释翻译
    [Configuration_adv.h]
2026-05-22 Translation--打印机暂停高级配置(Configuration_adv)注释翻译
    [Configuration_adv.h]
2026-05-22 Translation--TMC电机驱动高级配置(Configuration_adv)注释翻译
    [Configuration_adv.h]
2026-05-22 Translation--TMC驱动无传感器归位(Configuration_adv)注释翻译
    [Configuration_adv.h]
2026-05-22 Translation--I²C总线(Configuration_adv)注释翻译
    [Configuration_adv.h]
2026-05-22 Translation--摄像机录制配置(Configuration_adv)注释翻译
    [Configuration_adv.h]
2026-05-24 Translation--CNC相关配置（与3D打印机无关）注释翻译
    [Configuration_adv.h]
2026-05-24 Translation--耗材直径检测(Configuration_adv)注释翻译
    [Configuration_adv.h]
2026-05-24 Translation--电源安全监测(Configuration)注释翻译
    [Configuration_adv.h]
2026-05-24 Translation--反馈状态(Configuration_adv)注释翻译
    [Configuration_adv.h]
2026-05-24 Translation--Gcode相关(Configuration_adv)注释翻译
    [Configuration_adv.h]
2026-05-24 Translation--菜单、自定义按键(Configuration_adv)注释翻译
    [Configuration_adv.h]
2026-05-24 Translation--上位机通讯(Configuration_adv)注释翻译
    [Configuration_adv.h]
2026-05-26 Translation--电机闭环控制(Configuration_adv)注释翻译
    [Configuration_adv.h]
2026-05-26 Translation--一些杂七杂八的功能(Configuration_adv)注释翻译
    [Configuration_adv.h]
2026-05-26 Translation--WIFI功能配置(Configuration_adv)注释翻译
    [Configuration_adv.h]
2026-05-26 Translation--多色、多耗材打印配置(Configuration_adv)注释翻译
    [Configuration_adv.h]
2026-05-26 Translation--开发者高级配置(Configuration_adv)注释翻译
    [Configuration_adv.h]
2026-05-26 Improve--翻译优化-新增了一些通俗易懂的注释
    [Configuration.h]
2026-05-28 CAD图纸--上传了一些3D打印机结构件CAD图纸(搭配视频教程使用)
    [2mm不锈钢-42步进电机支架（适用于3030欧标铝型材）.dwg, 4mm不锈钢 Z轴热床托板.dwg, XY滑块与十字导轨连接件.dwg]
2026-05-28 CAD图纸--修改并上传了一些3D打印机结构件CAD图纸(搭配视频教程使用)
    [2mm不锈钢-42步进电机支架（适用于3030欧标铝型材）.dwg, 2mm不锈钢-XY滑块与十字导轨连接件.dwg, 2mm不锈钢-喷嘴处连接件.dwg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]
2026-06-05 Improve--翻译优化
    [Configuration.h]
2026-06-12 CAD图纸-打印机电源托板
    [10mm亚克力-电源托板.dwg, Configuration.h]
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2026-06-26 Improve--新增注解-自动调平，TMC2209驱动相关
    [Configuration.h, Configuration_adv.h]
2026-06-26 Improve--翻译优化-修改了一些翻译错误，优化中文注释排版布局
    [Configuration.h, Configuration_adv.h]
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2026-07-03 Revert "自定义引脚资源映射，自制主板pins.h文件"
    This reverts commit 0d7a13f68788e66a2260acf98f9728e4eb9068d9.
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2026-10-16 fix：修改了一些已知错误
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2026-11-09 fix: 移除主板 X2/Y2 DIAG 引脚以兼容 Klipper 无传感器回零
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

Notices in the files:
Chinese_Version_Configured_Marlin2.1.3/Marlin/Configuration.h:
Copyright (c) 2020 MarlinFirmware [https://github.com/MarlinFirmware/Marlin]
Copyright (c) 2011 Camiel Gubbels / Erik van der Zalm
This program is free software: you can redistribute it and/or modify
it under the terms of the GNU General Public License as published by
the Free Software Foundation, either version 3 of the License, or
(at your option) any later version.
